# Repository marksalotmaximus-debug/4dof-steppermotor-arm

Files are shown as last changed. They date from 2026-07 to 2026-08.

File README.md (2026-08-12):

# 4dof-steppermotor-arm
NOTES** Whole project is a WIP as of July 27th, and all code was written by either claude sonnet 5, or opus 4.8, I do understand this takes out a huge part of the challenge of the project, but as of right now my understanding of coding is very far from custom windows python based apps, more like a HELLO WORLD type situation with my skills in coding so far, I do plan on learning more, but the focus of this project was the design of the arm, the electronic layout of microcontrollers, and the integration of it all. A future project may be far more software sided, but this is a hardware and design as of right now.
credit for arduino uno firmware gcobos on github

### This arm is a 4DOF robotic arm using many parts from a broken creality Ender3 pro printer, all motors, and psu taken directly from that.

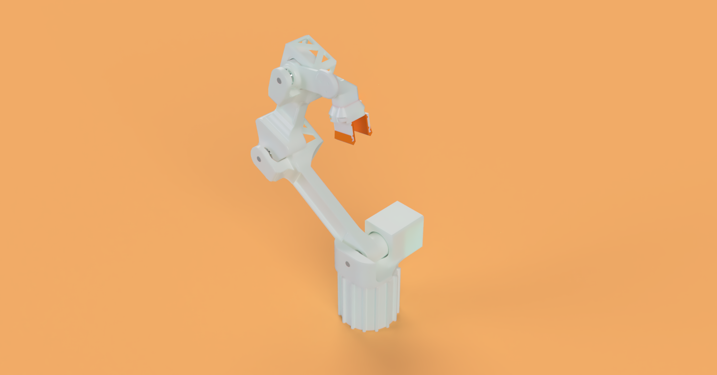
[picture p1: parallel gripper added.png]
Parallel Gripper
  
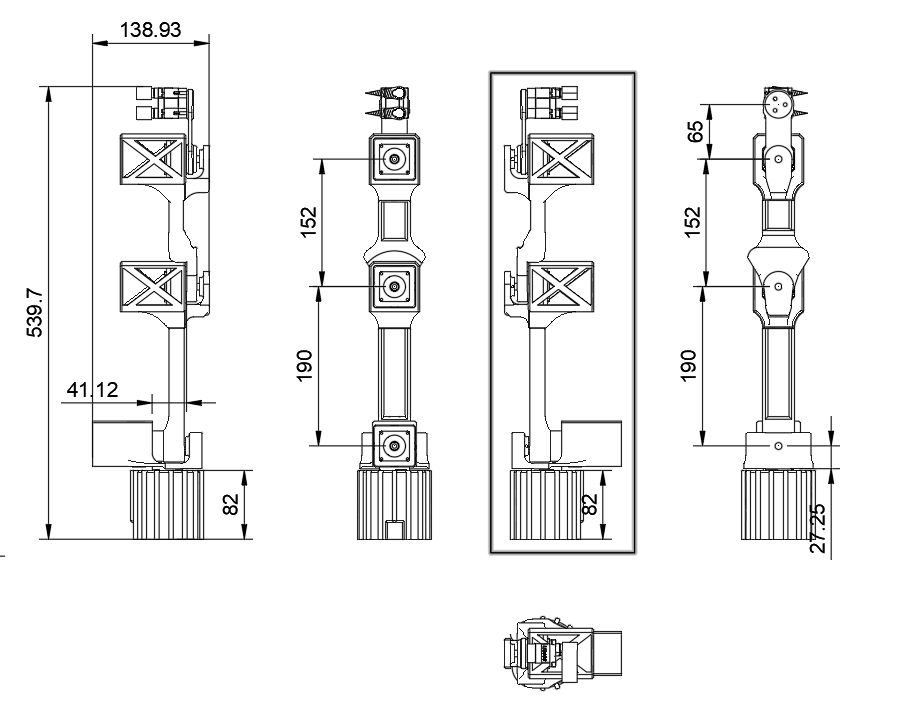
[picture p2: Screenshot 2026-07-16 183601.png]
  

  ### Arm Overview
  This arm has 3 segments of arm, with 4 degrees of freedom with a initial yaw control with the rest rotating on the YZ plane (for the most part with one of the three offset by a bit).
  The motor driving avoids expensive robotic actuators, and instead of servos for arm positioning (still servos in the gripper setup), I use a custom design modular stackable 6 to 1 planetary gear reduction, linked to NEMA17 stepper motors all taken from an Creality ender3 pro printer.
  All motors use a double stacked system of my gearboxes (36 to 1) except my wrist joint which only uses a 6 to 1 setup.
  Load is offset from gearboxes using a rather simple fork design where a aluminum rod on the opposite side of the segment side with the gearboxes is pushed through some bearings in order to drastically reduce load on fragile plastic gearboxes.

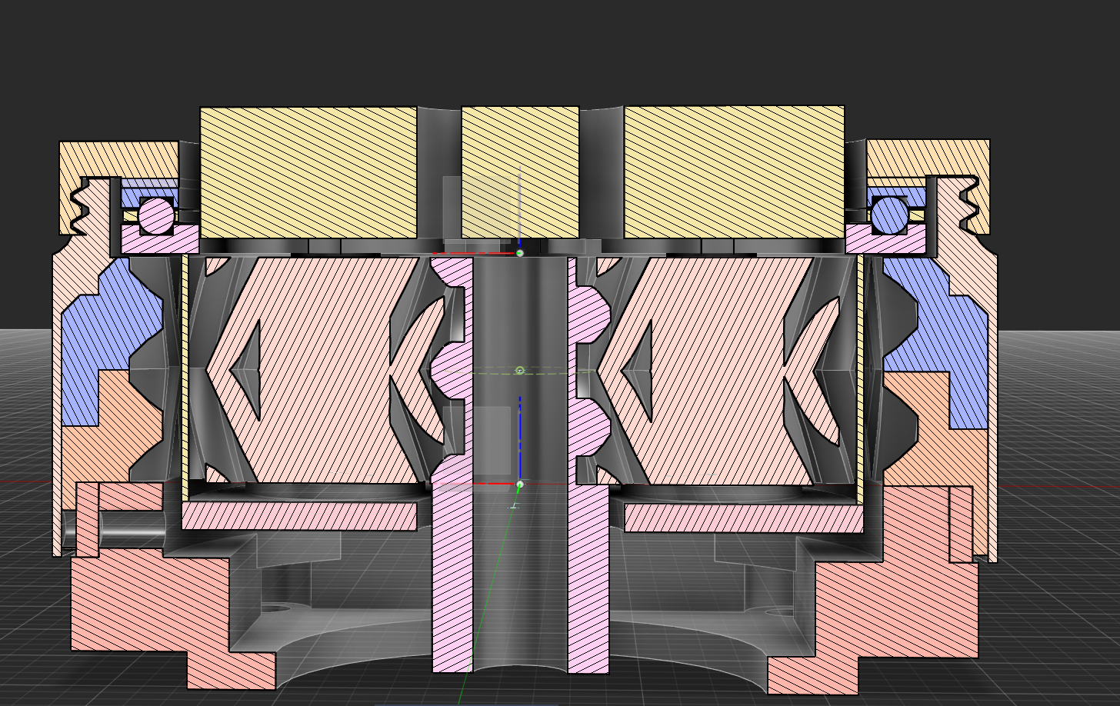
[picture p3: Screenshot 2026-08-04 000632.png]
  

  ### Arm control hardware

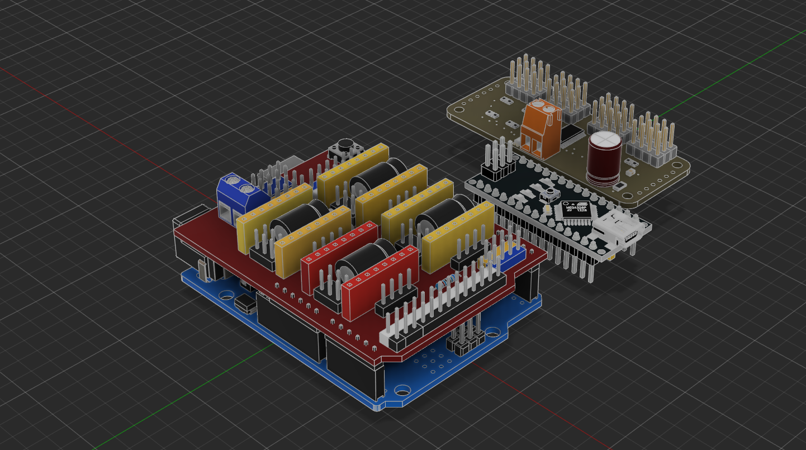
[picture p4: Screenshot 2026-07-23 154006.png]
  

  My design currently utilizes several widely available and cheap pcbs in order to deliver power and signal to motors.
    All systems controlled by a 24v psu taken out of a Ender3 printer, with an additional xt60 wired onto another V+ and V- for a separate output for Servo driving.
    Reason I split control over 2 microcontrollers was because gcobos/grbl4axis firmware uses almost all memory on the uno and adding a servo control function by repurposing existing i/o on my cnc shield would be irresponsible, and unstable.
    
  Stepper motor control loop
      Using a Arduino uno flashed with the open source grbl4axis firmware based off of pre 0.9 grbl firmware usually used for Cartesian CNC systems such as pen plotters and 3 axis milling machines, but split to allow for a 4th axis repurposed from a spindle control node.
      Connected to said arduino is a CNC shield v3 with DRV stepper motor drivers with full steps no microstepping, as well as pins D12 and D13 enabled for stepper control in place of a spindle.
      takes in standard grbl gcode for control.
  
  Servo control loop
      Using a arduino nano CH340 clone (doesnt really matter) wired up to a PCA9685 Servo control board, powered by a MP1584 buck converter tuned down from 24v to ~5v for stepper power.

  Arm control software
      Note all software other than grbl4axis firmware for the uno (open source credit gcobos) were written by either claude sonnet 5 or opus 4.8
      before starting up the main app you will need to run the setup which installs necessary libraries

  Communication is all handled by via COM ports from the uno and nano (so yes unfortunately you will need to plug each in separately to i/o on host computer)
      The app sends standard grbl4axis gcode over the uno COM ports, and a custom firmware and communication for the nano (very simple).
      All solving is handled by the host PC not the microcontrollers, simply too much compute for the little ATMEGA on the uno.

  Features: standard FK and IK solving and homing setup with custom DH params, Motion tuning (speed and acceleration), a kinda terrible waypoint IK motion setup, a much cooler text writing setup, and finally gripper control

  Just to talk about the IK solving math I went with since its so cool to me I go with a analytical geometric (no matrices) solver using the law of cosines and simplifying the problem by using a tool angle, and looking at yaw separately.

  ### Thanks for making a great opportunity to grow as a builder stardance!!

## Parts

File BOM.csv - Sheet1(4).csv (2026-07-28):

Item Name | Qty | Price (total) (USD) | Item link | Notes
Prusament PETG 2kg | 0 | $0.00 | https://www.printedsolid.com/products/prusament-petg-signal-white-2kg-made-in-usa | Alot of high quality high strength filament for prototyping and creating the many 3d parts for the arm
MG90S 9g servo | 2 | $8.88 | https://www.amazon.com/Miuzei-Geared-Helicopter-Arduino-Project/dp/B0BWJ4RKGV?th=1 | Servos for end effector of the arm
3 pin servo extension wire | 1 | $6.49 | https://www.amazon.com/Nvwadayu-Extension-Connector-Connectors-Quadcopter/dp/B0DJP3C2J7/ | Extension cables for servo (its at the end of the arm!)
NEMA 17 stepper motors | 4 | $0.00 | https://www.amazon.com/MOTOU%C2%AE-Nema17-Stepper-Motor-Efficient/dp/B0D41BSZWL/ | NOTE: ALREADY PAID AND OWNED DO NOT SEND TO ME
Arduino Uno | 1 | $0.00 | https://www.amazon.com/Arduino-UNO-Minima-ABX00080-Connector/dp/B0C78K4CD4/ | NOTE: ALREADY PAID AND OWNED DO NOT SEND TO ME
CNC Shield V3 & DRV8825 stepsticks | 1 | $0.00 | https://www.amazon.com/AITIAO-DRV8825-Expansion-Engraver-StepStick/dp/B0B24YS695 | NOTE: ALREADY PAID AND OWNED DO NOT SEND TO ME
24v power supply | 1 | $0.00 | https://www.amazon.com/NVVV-LRS-350-24-350-4W-Single-Switchable/dp/B08GPB8MK5/ | NOTE: ALREADY PAID AND OWNED DO NOT SEND TO ME
Stepper motor wires | 1 | $13.99 | https://www.amazon.com/REIFENG-Connector-Terminal-Paralled-Printer/dp/B07SLPLPL2/ | Not owned please send me, I need more wires
TPU | 1 | $0.00 | https://www.amazon.com/Overture-Filament-Flexible-Consumables-Dimensional/dp/B07VDP2S3P | NOTE: ALREADY PAID AND OWNED DO NOT SEND TO ME
M3 screws | 1 | $9.99 | https://www.amazon.com/Fgruh-750PCS-Assortment-Washers-Assorted/dp/B0FGV5FCBN | Needed for assembly in many parts of the arm
8mm aluminum round | 5 | $8.99 | https://www.amazon.com/Feelers-Aluminum-Round-Diameter-Length/dp/B0BNQ4Q87H/ | used in joint supports to offload pressure on gearboxes
608 sized bearings | 38 | $9.99 | https://www.amazon.com/Dianrui-Bearings-Assortment-Furniture-Printing/dp/B0GCM2LM74/ | used alongside aluminum bars for joint support
Mr105-2RS bearings | 40 | $0.00 | https://www.amazon.com/uxcell-Groove-Bearings-Metric-Double/dp/B082PRVZ7B?th=1 | NOTE: ALREADY PAID AND OWNED DO NOT SEND TO ME
PCA9685 board | 1 | $0.00 | https://www.amazon.com/PCA9685-Controller-Interface-Arduino-Raspberry/dp/B07ZNJRVHL?th=1 | NOTE: ALREADY PAID AND OWNED DO NOT SEND TO ME
Arduino Nano | 1 | $0.00 | https://www.amazon.com/AITRIP-Without-Connection-Compatible-Arduino/dp/B0B42GRG15/ | NOTE: ALREADY PAID AND OWNED DO NOT SEND TO ME
MP1584 | 1 | $0.00 | https://www.amazon.com/Diitao-MP1584EN-Adjustable-Converter-Voltage/dp/B0B2L477MJ?th=1 | NOTE: ALREADY PAID AND OWNED DO NOT SEND TO ME
Total Price (USD): | $58.33 | note: This is not the original request amount on the stardance side, however I realised that servos and a seperate controller was the most logical solution, and I also ordered my own filament because I wanted to start prototyping without waiting on funding

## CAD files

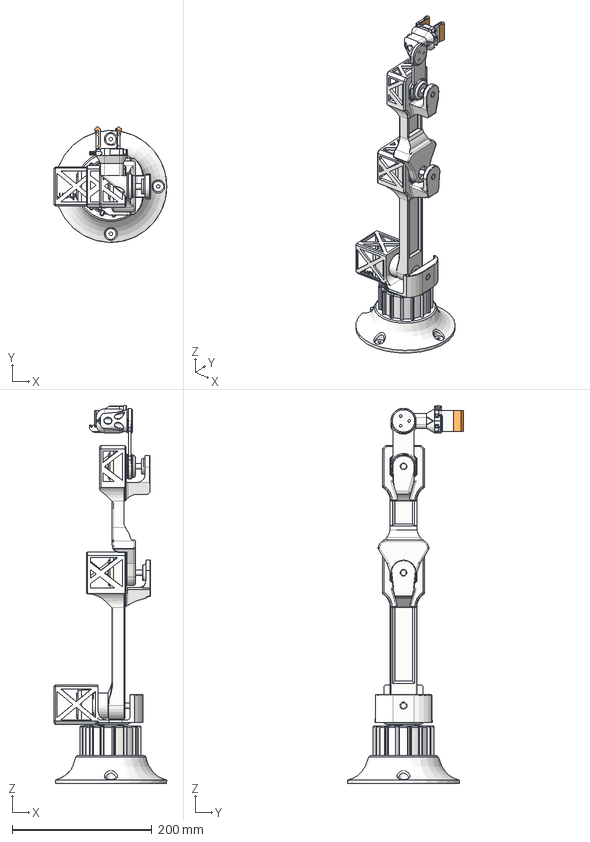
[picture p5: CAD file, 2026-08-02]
armrev81.step
161.1 x 165.6 x 540.3 mm
top bit of ring gear
Healical Gear (9R@25.00 m=0.8)
Healical Gear (18R@25.00 m=0.8) x 3
carrier bottom
adapter to nema
top and bottom ring gear unifier
top bit of ring gear (1)
Healical Gear (9R@25.00 m=0.8) (1)
Healical Gear (18R@25.00 m=0.8) (1) x 3
carrier bottom (1)
adapter to nema (1)
top and bottom ring gear unifier (1)
top bit of ring gear (2) x 2
Healical Gear (9R@25.00 m=0.8) (2) x 2
Healical Gear (18R@25.00 m=0.8) (2) x 6
carrier bottom (2) x 2
adapter to nema (2) x 2
top and bottom ring gear unifier (2) x 2
end effector
MG90S_step
connector to arm
Healical Gear (8R@30.00 m=1.5)(Mirror)
sliding assembly
parallel gripper v5 (1)
compliant tpu grippers
parallel gripper v5 (2)
compliant tpu grippers (1)
DIN 912 - M4 x 0.7 x 12 Steel 4.6 Plain
Base anchor

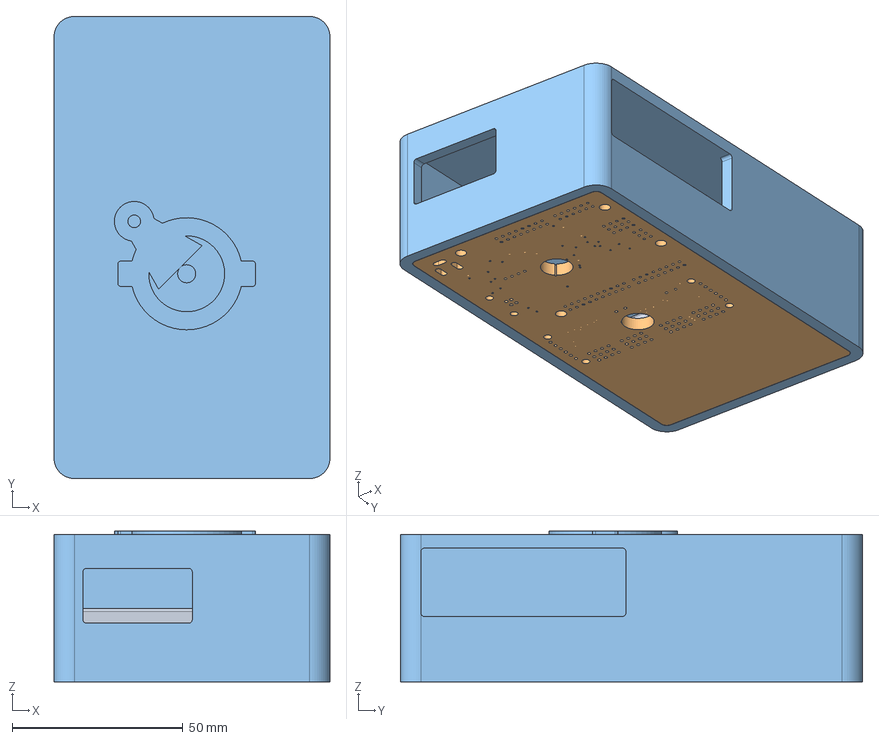
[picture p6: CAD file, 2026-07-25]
Electrics housing 724.step
80.8 x 135.3 x 44.2 mm
Nano mounting
pca and ard backing
Top lid

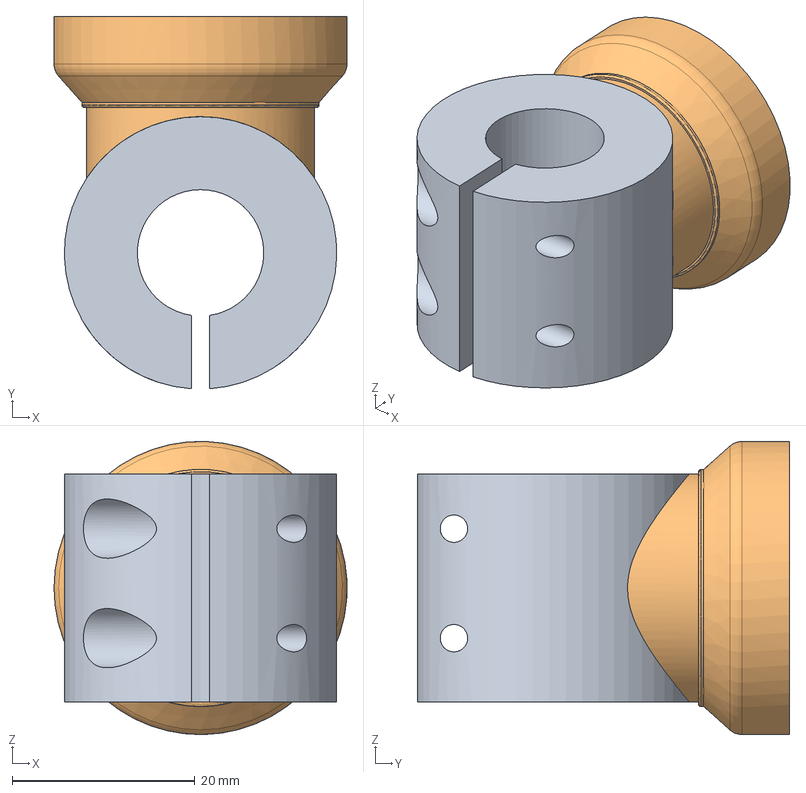
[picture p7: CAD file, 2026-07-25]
marker holder end effector 724.step
32.1 x 40.8 x 32.1 mm
Connector to arm
